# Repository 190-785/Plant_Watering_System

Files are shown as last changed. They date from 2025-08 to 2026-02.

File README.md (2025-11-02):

# Plant Watering System 🌱💧

An automated irrigation system using ESP8266 microcontrollers with soil moisture monitoring and intelligent watering control. Available in two versions: Basic IO and WiFi-enabled.

## Overview

This project consists of two main components with increasing levels of functionality:

### 1. IO Module (Basic Version)
A standalone irrigation controller that:
- Monitors soil moisture levels using an analog sensor
- Automatically controls a water pump based on moisture thresholds
- Provides real-time serial monitoring of system status
- Uses simple threshold-based logic for pump control

### 2. WiFi Module (Advanced Version)
An enhanced version with networking and cloud capabilities that includes:
- All basic irrigation functionality from the IO module
- WiFi connectivity with web-based configuration portal
- Firebase/Firestore integration for cloud data synchronization
- Real-time data synchronization to the cloud
- Remote configuration and control via Firebase
- Historical data logging and analytics
- Device-specific data paths using MAC address
- Web dashboard integration capabilities
- Data logging and remote monitoring capabilities
- Web server for system status and configuration
- JSON-based configuration management
- Button controls and LED status indicators
- Pump safety features and fault detection

## Hardware Requirements

### Core Components
- **Microcontroller**: ESP8266 (NodeMCU v2/v3)
- **Moisture Sensor**: Analog soil moisture sensor
- **Water Pump**: Small DC water pump (5V/12V)
- **Pump Driver**: ULN2003 or similar relay/driver circuit
- **Power Supply**: Appropriate for your pump voltage

### WiFi Version Additions
- **Push Button**: Momentary push button for manual controls
- **Status LED**: Single LED for status indication
- **WiFi Network**: 2.4GHz WiFi network for connectivity

### Wiring
- **Pump Control**: GPIO D1 (Pin 5) → ULN2003 IN1
- **Moisture Sensor**: A0 (Analog pin) → Sensor output
- **Button** (WiFi/Firebase): GPIO D2 (Pin 4) → Button + pull-up resistor
- **LED** (WiFi/Firebase): GPIO D3 (Pin 0) → LED anode
- **Power**: 3.3V/5V and GND connections as required

## Project Structure

```
Plant_Watering_System/
├── IO/                     # Basic irrigation system
│   ├── platformio.ini     # PlatformIO configuration
│   ├── src/
│   │   └── main.cpp       # Main irrigation logic
│   ├── include/           # Header files
│   └── lib/               # Local libraries
│
├── Wifi/                   # WiFi-enabled version
│   ├── platformio.ini     # PlatformIO configuration with WiFi libs
│   ├── src/
│   │   ├── main.cpp       # Main application with WiFi
│   │   ├── Config.cpp/h   # Configuration management
│   │   ├── ProvisionServer.cpp/h  # WiFi provisioning
│   │   └── PortalLogin.cpp/h      # Web portal authentication
│   ├── include/           # Header files
│   ├── lib/               # Local libraries
│   ├── HARDWARE_GUIDE.md  # Detailed hardware setup
│   ├── QUICK_REFERENCE.md # Quick reference card
│   ├── TESTING_MANUAL.md  # Manual testing procedures
│   └── TESTING_SIMULATION.md # Simulation testing guide
│
├── .gitignore             # Git ignore rules
├── LICENSE                # Project license
└── README.md              # This file
```

## Getting Started

### Prerequisites
- [PlatformIO IDE](https://platformio.org/platformio-ide) or [PlatformIO Core](https://platformio.org/install/cli)
- ESP8266 development board (NodeMCU recommended)
- Basic electronics components listed above

### Installation

1. **Clone the repository**:
   ```bash
   git clone https://github.com/190-785/Plant_Watering_System.git
   cd Plant_Watering_System
   ```

2. **Choose your version**:
   - For basic functionality: Navigate to `IO/` directory
   - For WiFi features: Navigate to `Wifi/` directory

3. **Build and upload**:
   ```bash
   # For basic version
   cd IO
   pio run --target upload

   # For WiFi version
   cd Wifi
   pio run --target upload
   ```

4. **Monitor serial output**:
   ```bash
   pio device monitor
   ```

### Configuration

#### Basic Version (IO)
- Power on the device near your plant
- Insert the moisture sensor into the soil
- Position the water pump in your water reservoir
- The system will automatically maintain optimal soil moisture

#### WiFi Version
1. **Initial Setup**: On first boot, the device creates a WiFi access point
2. **Connect**: Join the AP and navigate to the configuration portal
3. **Configure WiFi**: Set WiFi credentials and system parameters
4. **Firebase Setup** (Optional): Create a Firebase project and enable Firestore
5. **Configure Firebase** (Optional): Update `firebaseProjectId`, `firebaseApiKey`, and `firebaseDatabaseURL` in the code
6. **Deploy**: The system will connect to your network and begin operation, with optional cloud sync

## Features by Version

| Feature | IO | WiFi |
|---|----|---|
| Moisture monitoring | ✅ | ✅ |
| Automatic watering | ✅ | ✅ |
| Serial monitoring | ✅ | ✅ |
| Web interface | ❌ | ✅ |
| WiFi connectivity | ❌ | ✅ |
| Button controls | ❌ | ✅ |
| LED status | ❌ | ✅ |
| Pump safety | ❌ | ✅ |
| Data logging | ❌ | ✅ |
| Remote monitoring | ❌ | ✅ |
| Cloud sync | ❌ | ✅ |
| Historical data | ❌ | ✅ |

## Thresholds and Timing

### Moisture Control Logic
- **Dry Threshold**: 480-520 (triggers pump activation)
- **Wet Threshold**: 420-440 (stops pump operation)
- **Pump Runtime**: 1-2 seconds per cycle
- **Wait Period**: 1-2 minutes between pump cycles

### WiFi Version Features
- **Button Controls**: Triple-press (WiFi reset), Long-press (clear fault), Short-press (manual water)
- **LED Patterns**: 8 different status indicators
- **Web Endpoints**: Dashboard, status JSON, manual controls
- **Safety Features**: Pump interval enforcement, fault detection
- **Firebase Integration**: Real-time cloud synchronization, historical data logging
- **Device ID**: Auto-generated from MAC address
- **Data Paths**: `plantData/{deviceId}/` structure
- **Collections**: Live status, historical logs, remote config, commands
- **Sync Intervals**: Status every 10s, config check every 30s

## Documentation

### WiFi Version Documentation
- **[HARDWARE_GUIDE.md](Wifi/HARDWARE_GUIDE.md)** - Complete hardware setup and wiring
- **[QUICK_REFERENCE.md](Wifi/QUICK_REFERENCE.md)** - Quick reference card for controls and commands
- **[TESTING_MANUAL.md](Wifi/TESTING_MANUAL.md)** - Manual testing procedures and checklists
- **[TESTING_SIMULATION.md](Wifi/TESTING_SIMULATION.md)** - Simulation testing guide

## Customization

### Adjusting Thresholds
Modify the constants in `main.cpp`:
```cpp
constexpr uint16_t DRY_THRESHOLD = 520;  // Your dry value
constexpr uint16_t WET_THRESHOLD = 420;  // Your wet value
```

### Timing Adjustments
```cpp
const unsigned long PUMP_RUN_TIME = 1000;    // Pump duration (ms)
const unsigned long PUMP_WAIT_TIME = 60000;  // Wait between cycles (ms)
```

### WiFi Version Configuration
- **Portal Timeout**: 5 minutes for configuration
- **WiFi Retry**: Smart exponential backoff (1h → 6h → 24h)
- **Data Logging**: Every 30 seconds when online

### Firebase Configuration (WiFi Version)
Update these values in the WiFi version for cloud features:
```cpp
String firebaseProjectId = "your-project-id";
String firebaseApiKey = "your-api-key";
String firebaseDatabaseURL = "your-database-url";
```

## Troubleshooting

### Common Issues
- **Pump not activating**: Check wiring and power supply
- **Erratic readings**: Ensure sensor is properly inserted in soil
- **WiFi connection fails**: Verify credentials and signal strength
- **Continuous pumping**: Check sensor calibration and thresholds
- **Firebase sync fails**: Verify project credentials and permissions

### Version-Specific Issues

#### WiFi Version
- **Portal not appearing**: Triple-press button to force portal mode
- **LED not responding**: Check polarity (long leg to D3, short leg to GND)
- **Button not working**: Verify D2 connection and pull-up resistor
- **Firebase sync fails**: Check Firebase credentials and network connectivity
- **Device not appearing in Firebase**: Verify Firestore security rules
- **Firebase commands not working**: Check device ID format and collection paths

### Debugging
- Enable serial monitoring for detailed system status
- Check sensor readings manually with multimeter
- Verify pump operation with direct power connection
- Use the testing guides in the WiFi documentation

## Contributing

1. Fork the repository
2. Create a feature branch (`git checkout -b feature/amazing-feature`)
3. Commit your changes (`git commit -m 'Add amazing feature'`)
4. Push to the branch (`git push origin feature/amazing-feature`)
5. Open a Pull Request

## License

This project is licensed under the terms specified in the LICENSE file.

## Acknowledgments

- Built using PlatformIO and Arduino framework
- Designed for ESP8266 microcontrollers
- Inspired by the need for automated plant care solutions
- Firebase integration using Firebase Arduino Client Library

---

**Happy Growing! 🌱**

*Choose your version based on your needs:*
- **IO**: Simple, reliable, offline operation
- **WiFi**: Network connectivity, remote monitoring, and optional cloud features

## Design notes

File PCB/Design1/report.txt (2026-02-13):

Info: Processing symbol 'D1:LED_THT:LED_D5.0mm'.
Info: Processing symbol 'J1:Connector_PinHeader_2.54mm:PinHeader_1x02_P2.54mm_Vertical'.
Info: Processing symbol 'J2:Connector_PinHeader_2.54mm:PinHeader_1x03_P2.54mm_Vertical'.
Info: Processing symbol 'J3:Connector_PinHeader_2.54mm:PinHeader_1x15_P2.54mm_Vertical'.
Info: Processing symbol 'J4:Connector_PinHeader_2.54mm:PinHeader_1x15_P2.54mm_Vertical'.
Info: Processing symbol 'SW1:Button_Switch_THT:SW_PUSH-12mm'.
Info: Processing symbol 'U2:Package_DIP:DIP-16_W7.62mm'.
Info: Total warnings: 0, errors: 0.
Updated D1 symbol association from  to /114ef15a-0261-4e1b-b983-54d8c8b455e0.
Updated D1 fields.
Updated D1 sheetname to '/'.
Updated D1 sheetfile to 'Design1.kicad_sch'.
Updated D1 footprint filters to 'LED* LED_SMD:* LED_THT:*'.
Add net /3V3.
Connected D1 pin 1 to /3V3.
Add net unconnected-(D1-A-Pad2).
Connected D1 pin 2 to unconnected-(D1-A-Pad2).
Added J1 (footprint 'Connector_PinHeader_2.54mm:PinHeader_1x02_P2.54mm_Vertical').
Changed REF** reference designator to J1.
Changed J1 value from PinHeader_1x02_P2.54mm_Vertical to Screw_Terminal_01x02.
Updated J1 symbol association from  to /084adaf7-5e28-4bd0-8539-3aa2166aa7e4.
Updated J1 sheetname to '/'.
Updated J1 sheetfile to 'Design1.kicad_sch'.
Updated J1 footprint filters to 'TerminalBlock*:*'.
Connected J1 pin 1 to /3V3.
Connected J1 pin 2 to /3V3.
Added J2 (footprint 'Connector_PinHeader_2.54mm:PinHeader_1x03_P2.54mm_Vertical').
Changed REF** reference designator to J2.
Changed J2 value from PinHeader_1x03_P2.54mm_Vertical to Screw_Terminal_01x03.
Updated J2 symbol association from  to /2fd5f57d-fc6a-4e79-a7f4-4b87a4e682fe.
Updated J2 fields.
Updated J2 sheetname to '/'.
Updated J2 sheetfile to 'Design1.kicad_sch'.
Updated J2 footprint filters to 'TerminalBlock*:*'.
Connected J2 pin 2 to /3V3.
Connected J2 pin 1 to /3V3.
Connected J2 pin 3 to /3V3.
Updated J1 fields.
Added J3 (footprint 'Connector_PinHeader_2.54mm:PinHeader_1x15_P2.54mm_Vertical').
Changed REF** reference designator to J3.
Changed J3 value from PinHeader_1x15_P2.54mm_Vertical to Conn_01x15.
Updated J3 symbol association from  to /b5223ff5-7ecc-4eef-a9c0-85b9987116a3.
Updated J3 fields.
Updated J3 sheetname to '/'.
Updated J3 sheetfile to 'Design1.kicad_sch'.
Updated J3 footprint filters to 'Connector*:*_1x??_*'.
Add net /RX.
Connected J3 pin 4 to /RX.
Connected J3 pin 9 to /3V3.
Connected J3 pin 10 to /3V3.
Add net /TX.
Connected J3 pin 3 to /TX.
Connected J3 pin 14 to /3V3.
Add net /D8.
Connected J3 pin 5 to /D8.
Connected J3 pin 12 to /3V3.
Add net /D5.
Connected J3 pin 8 to /D5.
Add net /D0&apos;.
Connected J3 pin 15 to /D0&apos;.
Add net /D4.
Connected J3 pin 11 to /D4.
Add net /D6.
Connected J3 pin 7 to /D6.
Add net /D7.
Connected J3 pin 6 to /D7.
Connected J3 pin 1 to /3V3.
Add net /D2.
Connected J3 pin 13 to /D2.
Connected J3 pin 2 to /3V3.
Added J4 (footprint 'Connector_PinHeader_2.54mm:PinHeader_1x15_P2.54mm_Vertical').
Changed REF** reference designator to J4.
Changed J4 value from PinHeader_1x15_P2.54mm_Vertical to Conn_01x15.
Updated J4 symbol association from  to /26412373-530a-4317-82af-74bdb8bcc9cc.
Updated J4 fields.
Updated J4 sheetname to '/'.
Updated J4 sheetfile to 'Design1.kicad_sch'.
Updated J4 footprint filters to 'Connector*:*_1x??_*'.
Connected J4 pin 2 to /3V3.
Connected J4 pin 6 to /3V3.
Connected J4 pin 8 to /3V3.
Connected J4 pin 12 to /3V3.
Connected J4 pin 13 to /3V3.
Connected J4 pin 15 to /3V3.
Connected J4 pin 9 to /3V3.
Connected J4 pin 5 to /3V3.
Connected J4 pin 4 to /3V3.
Connected J4 pin 14 to /3V3.
Connected J4 pin 11 to /3V3.
Connected J4 pin 1 to /3V3.
Connected J4 pin 10 to /3V3.
Add net unconnected-(J4-Pin_3-Pad3).
Connected J4 pin 3 to unconnected-(J4-Pin_3-Pad3).
Connected J4 pin 7 to /3V3.
Added D1 (footprint 'LED_THT:LED_D5.0mm').
Added SW1 (footprint 'Button_Switch_THT:SW_PUSH-12mm').
Changed REF** reference designator to SW1.
Changed SW1 value from SW_PUSH-12mm to SW_Push.
Updated SW1 symbol association from  to /c2e4434d-4b0b-49ac-be75-4c2e37a08468.
Updated SW1 fields.
Updated SW1 sheetname to '/'.
Updated SW1 sheetfile to 'Design1.kicad_sch'.
Connected SW1 pin 2 to /3V3.
Connected SW1 pin 1 to /3V3.
Connected SW1 pin 1 to /3V3.
Connected SW1 pin 2 to /3V3.
Changed REF** reference designator to D1.
Added U2 (footprint 'Package_DIP:DIP-16_W7.62mm').
Changed REF** reference designator to U2.
Changed U2 value from DIP-16_W7.62mm to ULN2003.
Updated U2 symbol association from  to /411cef7f-ac7a-48d0-bb4d-53be7344f0cd.
Changed D1 value from LED_D5.0mm to LED.
Updated U2 sheetname to '/'.
Updated U2 sheetfile to 'Design1.kicad_sch'.
Updated U2 footprint filters to 'DIP*W7.62mm* SOIC*3.9x9.9mm*P1.27mm* SSOP*4.4x5.2mm*P0.65mm* TSSOP*4.4x5mm*P0.65mm* SOIC*W*5.3x10.2mm*P1.27mm*'.
Add net unconnected-(U2-I4-Pad4).
Connected U2 pin 4 to unconnected-(U2-I4-Pad4).
Add net unconnected-(U2-I6-Pad6).
Connected U2 pin 6 to unconnected-(U2-I6-Pad6).
Add net unconnected-(U2-I2-Pad2).
Connected U2 pin 2 to unconnected-(U2-I2-Pad2).
Add net unconnected-(U2-O2-Pad15).
Connected U2 pin 15 to unconnected-(U2-O2-Pad15).
Add net unconnected-(U2-O7-Pad10).
Connected U2 pin 10 to unconnected-(U2-O7-Pad10).
Add net unconnected-(U2-COM-Pad9).
Connected U2 pin 9 to unconnected-(U2-COM-Pad9).
Connected U2 pin 1 to /3V3.
Add net unconnected-(U2-O3-Pad14).
Updated U2 fields.
Add net unconnected-(U2-O6-Pad11).
Connected U2 pin 11 to unconnected-(U2-O6-Pad11).
Add net unconnected-(U2-GND-Pad8).
Connected U2 pin 8 to unconnected-(U2-GND-Pad8).
Add net unconnected-(U2-O5-Pad12).
Connected U2 pin 12 to unconnected-(U2-O5-Pad12).
Add net unconnected-(U2-I3-Pad3).
Connected U2 pin 3 to unconnected-(U2-I3-Pad3).
Add net unconnected-(U2-I7-Pad7).
Connected U2 pin 7 to unconnected-(U2-I7-Pad7).
Add net unconnected-(U2-O4-Pad13).
Connected U2 pin 13 to unconnected-(U2-O4-Pad13).
Connected U2 pin 16 to /3V3.
Add net unconnected-(U2-I5-Pad5).
Connected U2 pin 5 to unconnected-(U2-I5-Pad5).

Connected U2 pin 14 to unconnected-(U2-O3-Pad14).

Info: Total warnings: 0, errors: 0.

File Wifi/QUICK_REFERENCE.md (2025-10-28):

# Quick Reference Card - Smart Irrigation System v3.0

## 🎮 Button Controls (D2)
```
┌─────────────────────────────────────────────┐
│  Triple Press  │ 3 clicks in 2 seconds      │ → WiFi Reset
│  Long Press    │ Hold 5+ seconds            │ → Clear Fault  
│  Short Press   │ Quick click                │ → Manual Water
└─────────────────────────────────────────────┘
```

## 💡 LED Patterns (D3)
```
Portal Active    ●●──●●──  Fast double-blink
Connecting       ●───●───  Fast blink
Online           ●────────  Slow heartbeat (every 3s)
Offline          ●────────  Slow blink (every 3s)
Pumping          ████████  Solid on
Fault            ●●────●●  Error blink
Button Feedback  ●●●       Three flashes
```

## 📍 Pin Mapping
```
D1 → Pump (via ULN2003)
D2 → Button (+ pull-up)
D3 → LED Anode
A0 → Moisture Sensor
```

## 🌐 Network
```
AP Name:  Irrigation-Setup
Password: plant123456
Web UI:   http://{device-ip}/
```

## 🔗 Web Endpoints
```
GET  /         → Dashboard
GET  /status   → JSON status
POST /water    → Manual water
POST /clearFault → Clear fault
POST /resetWiFi → Reset config
```

## 📊 Firestore Paths
```
plantData/{deviceId}/
  ├── (document)           → Live status
  ├── logs/{timestamp}     → Historical data
  ├── config/settings      → Configuration
  └── commands/pending     → Remote commands
```

## ⚙️ Default Config (Testing)
```
Dry Threshold:   520
Wet Threshold:   420
Pump Run Time:   2000 ms (2 sec)
Min Interval:    60 sec (1 min)
No-Effect Max:   2 failures
Settle Time:     10000 ms (10 sec)
```

## 🔄 State Transitions
```
AWAITING_CONFIG → ONLINE → OFFLINE ⟲
                    ↓
              LOCKED_FAULT (clearable)
```

## 🚨 Common Issues
```
No WiFi      → Triple-press button
Pump stuck   → Check ULN2003 wiring
Fault locked → Long-press 5 seconds
LED wrong    → Check polarity (long leg = +)
```

## 📝 Serial Monitor Commands
```
115200 baud
Look for:
  ✓ = Success
  ✗ = Error
  ⚠ = Warning
  [STATUS] = Regular update
  [BUTTON] = Button event
  [WiFi] = Network event
```

## 🎯 Quick Test Sequence
```
1. Power on
2. Watch LED (should show portal or connecting)
3. Press button once (LED should flash 3x)
4. Check serial for "BUTTON Short press"
5. Dry sensor (should auto-water)
6. Check Firebase console for logs
```

## 📱 Firebase Update Example
```javascript
// Update config
db.collection('plantData')
  .doc(deviceId)
  .collection('config')
  .doc('settings')
  .update({
    dryThreshold: 530,
    pumpRunTime: 5000
  });

// Clear fault
db.collection('plantData')
  .doc(deviceId)
  .collection('commands')
  .doc('pending')
  .set({
    clearFault: true
  });
```

## 🔐 Default Credentials
```
Firebase Project: bloom-watch-d6878
API Key: AIzaSyCt74... (in code)
Device ID: ESP8266_{MAC} (auto-generated)
```

## ⏱️ Timing Reference
```
Data Send:        Every 10 seconds
Config Check:     Every 30 seconds
Status Display:   Every 3 seconds
WiFi Check:       Every 5 seconds
Smart Retry:      1h → 6h → 24h
Portal Timeout:   5 minutes
```

## 💾 Files
```
/config.json       → WiFi & Firebase creds
/pump_state.json   → Pump history & faults
```

## 🛠️ Build Commands
```
pio run --target upload    → Flash device
pio device monitor         → View serial
pio run --target clean     → Clean build
```

## 📞 Emergency Recovery
```
1. Triple-press button → Force portal
2. Connect to "Irrigation-Setup"
3. Reconfigure WiFi
4. Or: Flash with USB cable
```

## ✅ Deployment Checklist
```
□ Hardware connected per diagram
□ Firebase credentials verified
□ Libraries installed
□ Code compiles
□ First boot shows portal
□ WiFi connects
□ LED shows correct pattern
□ Button presses register
□ Pump activates
□ Firebase logs appear
□ Web interface accessible
```

---

**Keep this card handy during testing!** 📋

Print or save for quick reference while working with your device.

Version: 3.0 Phase 1 | ESP8266 NodeMCU | Firebase Firestore

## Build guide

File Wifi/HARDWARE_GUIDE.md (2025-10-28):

# Hardware Connection Guide
## Smart Irrigation System - ESP8266 NodeMCU

```
┌─────────────────────────────────────────────────────────────┐
│                     HARDWARE WIRING DIAGRAM                  │
└─────────────────────────────────────────────────────────────┘

╔═══════════════════════════════════════════════════════════╗
║                    NodeMCU ESP8266                         ║
║                                                            ║
║  [USB] ←── Power & Programming                            ║
║                                                            ║
║  3V3  ●────────────────────────┐                          ║
║                                 │                          ║
║  GND  ●──────┬──────┬──────────┼──────┬──────────┐       ║
║              │      │          │      │          │       ║
║  VIN  ●──────┼──────┼──────────┼──────┼────┐     │       ║
║              │      │          │      │    │     │       ║
║   D1  ●──────┼──────┼────┐     │      │    │     │       ║
║              │      │    │     │      │    │     │       ║
║   D2  ●──────┼──────┼────┼────┐│      │    │     │       ║
║              │      │    │     ││      │    │     │       ║
║   D3  ●──────┼──────┼────┼────┼┼────┐ │    │     │       ║
║              │      │    │     ││    │ │    │     │       ║
║   A0  ●──────┼──────┼────┼────┼┼────┼─┼────┼───┐ │       ║
║              │      │    │     ││    │ │    │   │ │       ║
╚══════════════╪══════╪════╪═════╪╪════╪═╪════╪═══╪═╪═══════╝
               │      │    │     ││    │ │    │   │ │
               │      │    │     ││    │ │    │   │ │
    ┌──────────┘      │    │     ││    │ │    │   │ │
    │                 │    │     ││    │ │    │   │ │
╔═══▼═════════════════▼════▼═════▼▼════▼═▼════▼═══▼═▼═══════╗
║              ULN2003 Darlington Driver                      ║
╠═══════════════════════════════════════════════════════════╣
║  IN1  (from D1)                                            ║
║  IN2-7  (not used)                                         ║
║  GND   (from NodeMCU GND)                                  ║
║  COM   (from NodeMCU VIN)  ←── Power for pump             ║
║  OUT1  ────────┐                                           ║
╚════════════════╪═══════════════════════════════════════════╝
                 │
                 │         ╔════════════════════╗
                 └────────→║   WATER PUMP       ║
                           ║   Pin 1: Signal    ║
                           ║   Pin 2: VIN       ║
                           ╚════════════════════╝

╔═══════════════════════════════════════════════════════════╗
║              Capacitive Moisture Sensor                    ║
╠═══════════════════════════════════════════════════════════╣
║  VCC  → NodeMCU 3V3                                        ║
║  GND  → NodeMCU GND                                        ║
║  AOUT → NodeMCU A0                                         ║
╚═══════════════════════════════════════════════════════════╝

╔═══════════════════════════════════════════════════════════╗
║                Manual Control Button                       ║
╠═══════════════════════════════════════════════════════════╣
║  Terminal 1 → NodeMCU D2                                   ║
║  Terminal 2 → NodeMCU GND                                  ║
║                                                            ║
║  Note: Internal pull-up enabled in software               ║
╚═══════════════════════════════════════════════════════════╝

╔═══════════════════════════════════════════════════════════╗
║                    Status LED                              ║
╠═══════════════════════════════════════════════════════════╣
║  Anode (+, long leg)  → NodeMCU D3                        ║
║  Cathode (-, short leg) → NodeMCU GND                     ║
║                                                            ║
║  Note: Built-in current limiting in ESP8266 GPIO          ║
║        If LED too bright, add 220Ω resistor in series     ║
╚═══════════════════════════════════════════════════════════╝
```

---

## Pin Summary Table

| Component | NodeMCU Pin | Wire Color (Suggested) | Notes |
|---|---|---|---|
| **Pump Control** | D1 | Yellow | To ULN2003 IN1 |
| **Moisture Sensor**| A0 | White | Analog reading |
| **Button** | D2 | Blue | Pull-up enabled |
| **Status LED** | D3 | Green | Anode (long leg) |
| **Sensor VCC** | 3V3 | Red | 3.3V power |
| **Common Ground**  | GND | Black | Multiple connections |
| **Pump Power** | VIN | Red (thick) | 5V from USB |

---

## Component Details

### 1. ULN2003 Darlington Driver Pinout
```
        ┌─────────┐
   IN1 →│1      16│→ OUT1 (to pump)
   IN2 →│2      15│
   IN3 →│3      14│
   IN4 →│4      13│
   IN5 →│5      12│
   IN6 →│6      11│
   IN7 →│7      10│
   GND ─│8       9│─ COM (VIN power)
        └─────────┘
```

### 2. Button Wiring Options
```
Option A: Simple (Used in Code)
┌──────┐
│  D2  ●───────┬─── Button Terminal 1
│      │       │
│ GND  ●───────┴─── Button Terminal 2
└──────┘
Internal pull-up: Button not pressed = HIGH, pressed = LOW

Option B: External Pull-up (if internal not reliable)
┌──────┐
│ 3V3  ●─── 10kΩ resistor ───┬─── Button Terminal 1
│      │                      │
│  D2  ●──────────────────────┤
│      │                      │
│ GND  ●──────────────────────┴─── Button Terminal 2
└──────┘
```

### 3. LED Polarity Identification
```
        LED
    ┌────────┐
    │  ╱╲    │
    │ ╱  ╲   │ ← Flat edge on cathode side
    │╱____╲  │
    │   ||   │
    │   ||   │
    └───┬┬───┘
        ││
    Long│  Short
  (Anode)  (Cathode)
     +       -
     D3     GND
```

---

## Testing Individual Components

### Test 1: LED
```cpp
void setup() {
  pinMode(D3, OUTPUT);
}
void loop() {
  digitalWrite(D3, HIGH);
  delay(1000);
  digitalWrite(D3, LOW);
  delay(1000);
}
```
**Expected:** LED blinks on/off every second

### Test 2: Button
```cpp
void setup() {
  Serial.begin(115200);
  pinMode(D2, INPUT_PULLUP);
}
void loop() {
  Serial.println(digitalRead(D2));
  delay(100);
}
```
**Expected:** Prints "1" normally, "0" when button pressed

### Test 3: Moisture Sensor
```cpp
void setup() {
  Serial.begin(115200);
}
void loop() {
  Serial.println(analogRead(A0));
  delay(500);
}
```
**Expected:** 
- In air: ~800-1024
- In water: ~200-400
- In moist soil: ~400-600
- In dry soil: ~600-800

### Test 4: Pump (CAREFUL!)
```cpp
void setup() {
  pinMode(D1, OUTPUT);
  digitalWrite(D1, LOW);
}
void loop() {
  digitalWrite(D1, HIGH);  // ON
  delay(2000);
  digitalWrite(D1, LOW);   // OFF
  delay(10000);
}
```
**Expected:** Pump runs 2 seconds, off 10 seconds, repeat
**WARNING:** Have water reservoir connected!

---

## Power Requirements

| Component | Voltage | Current | Source |
|---|---|---|---|
| ESP8266 NodeMCU | 3.3V | ~80mA | USB 5V (onboard regulator) |
| Moisture Sensor | 3.3V | ~5mA | NodeMCU 3V3 |
| LED | 2-3V | ~20mA | NodeMCU D3 |
| Button | 3.3V | <1mA | NodeMCU D2 |
| Water Pump (typical) | 3-6V | 100-200mA | USB 5V (VIN)  |
| ULN2003 (driver IC) | 5V | <1mA | NodeMCU VIN |

**Total Current Draw:**
- Idle: ~85mA
- Pump Running: ~285mA
- **USB Port Limit:** 500mA (safe margin)

---

## Common Issues & Solutions

### Issue: Pump doesn't run
**Solutions:**
1. Check D1 connection to ULN2003 IN1
2. Verify ULN2003 GND connected to NodeMCU GND
3. Verify ULN2003 COM connected to NodeMCU VIN
4. Check pump polarity (try reversing if DC pump)
5. Test with multimeter: Should see ~5V on OUT1 when D1 HIGH

### Issue: LED always on/off
**Solutions:**
1. Check LED polarity (swap if backwards)
2. Verify anode (long leg) to D3
3. Verify cathode (short leg) to GND
4. Test with: `digitalWrite(D3, HIGH);` in setup()

### Issue: Button always pressed/never pressed
**Solutions:**
1. Check wiring: One side D2, other side GND
2. Try different button (could be faulty)
3. Test with multimeter: Should be open circuit normally, closed when pressed

### Issue: Moisture readings don't change
**Solutions:**
1. Verify sensor VCC to 3V3 (NOT 5V!)
2. Check AOUT to A0 connection
3. Check GND connection
4. Test in glass of water - should drop significantly

### Issue: ESP8266 resets when pump runs
**Solutions:**
1. Likely power issue - pump drawing too much current
2. Add capacitor (100µF-1000µF) across VIN and GND
3. Use separate 5V power supply for pump
4. Reduce pump runtime or use smaller pump

---

## Safety Checklist

- [ ] All connections secure (no loose wires)
- [ ] No exposed metal touching other components
- [ ] Moisture sensor fully waterproof (only prongs in soil/water)
- [ ] Water reservoir below electronics (prevent spills on board)
- [ ] USB power supply rated for 1A or higher
- [ ] No water near USB port or ESP8266
- [ ] Pump has water to pump (don't run dry)
- [ ] First test without water, verify pump spins

---

## Recommended Tools

- **Multimeter** - For voltage/continuity testing
- **Breadboard** - For prototyping before soldering
- **Jumper Wires** - Male-to-male, male-to-female
- **USB Cable** - Micro USB for NodeMCU power/programming
- **Screwdriver** - For ULN2003 terminal blocks
- **Wire Strippers** - If using solid core wire

---

## Final Assembly Tips

1. **Test each component individually first** (see test code above)
2. **Use breadboard for initial testing** before permanent connections
3. **Label all wires** with masking tape (component name + pin)
4. **Take photos** of working setup before making changes
5. **Keep moisture sensor away from electronics**
6. **Mount NodeMCU above water level**
7. **Use cable ties** to organize wires
8. **Add strain relief** on USB cable

---

**All connections verified against system design specification.**

Ready to build! 🛠️

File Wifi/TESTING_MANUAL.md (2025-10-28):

# 🧪 Smart Irrigation System - Manual Test Plan (Phase 1)

## 📋 Test Overview
This document provides a comprehensive manual testing checklist for all Phase 1 features. Each test includes:
- **Prerequisites** - What needs to be ready
- **Steps** - Exact procedure to follow
- **Expected Result** - What should happen
- **Pass/Fail Criteria** - How to verify success

---

## 🔧 Pre-Test Setup

### Hardware Checklist
- [ ] ESP8266 NodeMCU connected via USB
- [ ] Button connected to D2 (GPIO4) with pull-up resistor
- [ ] LED connected to D3 (GPIO0) with current-limiting resistor
- [ ] Pump connected to D1 (GPIO5) via ULN2003 driver
- [ ] Moisture sensor connected to A0
- [ ] Power supply adequate for all components

### Software Checklist
- [ ] Code uploaded successfully (no compilation errors)
- [ ] Serial monitor open at 115200 baud
- [ ] Firebase console open: https://console.firebase.google.com/project/bloom-watch-d6878/firestore
- [ ] Device ID noted from serial output (ESP8266_XXXXXXXXXXXX)

---

## ✅ TEST SUITE 1: INITIALIZATION & BOOT

### Test 1.1: First Boot (No Config)
**Prerequisites:** Flash empty filesystem (erase flash)
```bash
pio run --target erase
pio run --target upload
```

**Steps:**
1. Reset ESP8266
2. Observe serial output
3. Check LED pattern

**Expected Results:**
```
✓ LittleFS mounted successfully
Device ID: ESP8266_C82B9622AF07
ℹ No config file found - will create on first WiFi connection
ℹ No WiFi config - starting portal
*wm:StartAP with SSID: Irrigation-Setup
*wm:AP IP address: 192.168.4.1
```
- LED shows **fast double-blink** (100ms on, 100ms off, 100ms on, 700ms off)
- WiFi AP "Irrigation-Setup" visible in WiFi list

**Pass Criteria:**
- [ ] Portal AP broadcasts
- [ ] LED shows correct pattern
- [ ] Serial shows no errors

---

### Test 1.2: Boot with Saved Config
**Prerequisites:** WiFi already configured

**Steps:**
1. Reset ESP8266
2. Observe connection sequence

**Expected Results:**
```
✓ Configuration loaded
✓ Attempting WiFi connection...
✓ Connected! IP: 192.168.x.x
✓ Web server started on port 80
State: ONLINE
```
- LED shows **slow heartbeat** (100ms pulse every 3 seconds)
- Device connects to WiFi within 30 seconds

**Pass Criteria:**
- [ ] Connects to saved WiFi
- [ ] Gets IP address
- [ ] Shows ONLINE state
- [ ] LED heartbeat visible

---

## ✅ TEST SUITE 2: BUTTON CONTROLS

### Test 2.1: Short Press (Manual Water)
**Prerequisites:** Device ONLINE, no fault, >60 seconds since last pump

**Steps:**
1. Press and release button quickly (< 1 second)
2. Observe LED feedback
3. Watch for pump activation
4. Check serial output

**Expected Results:**
```
[BUTTON] Short press detected
[PUMP] Manual activation requested
[PUMP] Starting pump (Manual)
[STATUS] Moisture: XXX | Pump: PUMP_RUNNING | Device: ONLINE
```
- LED flashes 3 times quickly (button feedback)
- LED goes solid for 2 seconds (pumping)
- Pump relay activates for 2 seconds
- Returns to MONITORING state

**Pass Criteria:**
- [ ] Button feedback visible
- [ ] Pump runs for exactly 2 seconds
- [ ] Moisture reading taken before/after
- [ ] Logged to Firestore

---

### Test 2.2: Long Press (Clear Fault)
**Prerequisites:** Device in LOCKED_FAULT state

**Steps:**
1. Create fault condition (trigger no-effect detection twice)
2. Press and hold button for 5+ seconds
3. Release button
4. Observe state change

**Expected Results:**
```
[BUTTON] Long press detected
[FAULT] Clearing fault state
✓ Fault cleared via button
State: ONLINE
```
- LED changes from slow error blink to heartbeat
- Fault counter resets to 0
- Device returns to ONLINE state
- Pump state saved to flash

**Pass Criteria:**
- [ ] Fault clears after 5 seconds hold
- [ ] State changes to ONLINE
- [ ] LED pattern updates
- [ ] pump_state.json updated

---

### Test 2.3: Triple Press (WiFi Reset)
**Prerequisites:** Device running (any state)

**Steps:**
1. Press button 3 times within 2 seconds
2. Wait for portal to start
3. Check WiFi AP list

**Expected Results:**
```
[BUTTON] Triple press detected
[WiFi] Force configuration portal
*wm:StartAP with SSID: Irrigation-Setup
State: AWAITING_CONFIG
```
- LED switches to fast double-blink
- "Irrigation-Setup" AP appears
- Web portal accessible at 192.168.4.1
- Can reconfigure WiFi

**Pass Criteria:**
- [ ] Portal starts immediately
- [ ] AP broadcasts within 5 seconds
- [ ] Portal accessible
- [ ] Can save new config

---

## ✅ TEST SUITE 3: LED PATTERNS

### Test 3.1: All LED Patterns Visual Verification

| State | Pattern | Timing | How to Trigger |
|---|---|---|---|
| **Portal Active** | Fast double-blink | 100ms on, 100ms off, 100ms on, 700ms off | Triple press button |
| **Connecting** | Fast single blink | 200ms on, 800ms off | Reboot with WiFi config, disconnect router |
| **Online** | Slow heartbeat | 100ms on every 3000ms | Normal operation when connected |
| **Offline** | Single blink | 500ms on every 3000ms | Disconnect WiFi router |
| **Pumping** | Solid on | Continuous | Trigger manual water or auto water |
| **Fault** | Slow error blink | 500ms on, 1500ms off | Trigger fault (2x no-effect) |
| **Button Feedback** | Three quick flashes | 50ms on/off x3 | Press any button |
| **Off** | No light | - | Not used in Phase 1 |

**Steps:**
1. For each state, trigger the condition
2. Use stopwatch/timer to verify exact timing
3. Record visual observation

**Pass Criteria:**
- [ ] All 8 patterns visually distinct
- [ ] Timing matches specification ±10ms
- [ ] Patterns persist correctly
- [ ] Transitions smooth

---

## ✅ TEST SUITE 4: PUMP SAFETY LOGIC

### Test 4.1: Minimum Interval Enforcement (AUTO)
**Prerequisites:** Device ONLINE, dry soil (moisture < 520)

**Steps:**
1. Allow auto-watering to trigger
2. Immediately trigger auto again (dry sensor reading)
3. Check serial output

**Expected Results:**
```
[PUMP] Auto activation requested
[SAFETY] minInterval not met: 30/60 seconds elapsed
```
- Pump does NOT activate second time
- Must wait full 60 seconds
- LED does not show pumping pattern

**Pass Criteria:**
- [ ] Second pump attempt blocked
- [ ] Serial shows safety message
- [ ] Wait 60s → then pump works

---

### Test 4.2: Minimum Interval Enforcement (MANUAL)
**Prerequisites:** Device ONLINE

**Steps:**
1. Short press button (manual water)
2. Wait for pump to finish
3. Immediately short press again
4. Check response

**Expected Results:**
```
[PUMP] Manual activation requested
[SAFETY] minInterval not met: 5/60 seconds elapsed
```
- Second manual request blocked
- Same 60-second rule applies
- Button feedback still shows

**Pass Criteria:**
- [ ] Manual also respects minInterval
- [ ] Safety message appears
- [ ] No pump activation

---

### Test 4.3: No-Effect Detection (First Occurrence)
**Prerequisites:** Device ONLINE, moisture sensor NOT in water

**Steps:**
1. Place sensor in dry air (not in soil)
2. Trigger manual water (short press)
3. Wait for pump to run and settle (12 seconds total)
4. Check serial output

**Expected Results:**
```
[PUMP] Starting pump (Manual)
[PUMP] Before: 100, After: 105, Delta: 5
⚠ Pump ineffective! No significant moisture change (5 < 30)
⚠ No-effect count: 1/2
```
- No-effect counter increments to 1
- Device stays in ONLINE state
- Pump state saved
- Still allows next watering attempt

**Pass Criteria:**
- [ ] Delta calculated correctly
- [ ] Counter = 1 (not locked yet)
- [ ] State remains ONLINE
- [ ] pump_state.json shows noEffectCounter: 1

---

### Test 4.4: Fault Locking (Second No-Effect)
**Prerequisites:** No-effect counter = 1

**Steps:**
1. Wait 60+ seconds (minInterval)
2. Sensor still dry (no water)
3. Trigger manual water again
4. Observe state change

**Expected Results:**
```
[PUMP] Before: 100, After: 103, Delta: 3
⚠ Pump ineffective! No significant moisture change (3 < 30)
⚠ No-effect count: 2/2
🚨 FAULT LOCKED - Too many ineffective pump cycles!
State: LOCKED_FAULT
```
- LED switches to slow error blink (500ms/1500ms)
- Device enters LOCKED_FAULT state
- Auto watering disabled
- Manual watering disabled
- Fault persists across reboots

**Pass Criteria:**
- [ ] Counter reaches 2
- [ ] State = LOCKED_FAULT
- [ ] LED error pattern
- [ ] Persists after reboot
- [ ] Pump blocked for all triggers

---

### Test 4.5: Fault Recovery
**Prerequisites:** Device in LOCKED_FAULT

**Steps:**
1. Long press button (5 seconds)
2. Observe state change
3. Reset device
4. Check state persists

**Expected Results:**
```
[BUTTON] Long press detected
[FAULT] Clearing fault state
✓ Fault cleared via button
State: ONLINE
```
- Counter resets to 0
- Device returns to ONLINE
- LED shows heartbeat
- pump_state.json updated

**Pass Criteria:**
- [ ] Fault clears successfully
- [ ] Counter = 0
- [ ] State = ONLINE after reboot
- [ ] Can pump again (respecting minInterval)

---

## ✅ TEST SUITE 5: WIFI & CONNECTIVITY

### Test 5.1: WiFi Portal Configuration
**Prerequisites:** Fresh device or triple-press to reset

**Steps:**
1. Connect phone/PC to "Irrigation-Setup" AP
2. Password: plant123456
3. Browser should auto-open to 192.168.4.1
4. Configure WiFi network
5. Click "Save"

**Expected Results:**
- Portal loads showing available networks
- Can select network and enter password
- After save, device reboots and connects
- config.json created in filesystem

**Pass Criteria:**
- [ ] Portal accessible
- [ ] Networks listed
- [ ] Can save configuration
- [ ] Device connects after save

---

### Test 5.2: Smart Retry - First Failure (1 hour)
**Prerequisites:** Device connected to WiFi

**Steps:**
1. Disconnect/turn off router
2. Observe retry behavior
3. Check serial output timing

**Expected Results:**
```
✗ WiFi connection lost
State: OFFLINE
Retry attempt: 1, Next retry in: 60 minutes
```
- Device switches to OFFLINE
- LED shows single blink pattern
- Retries connection after 1 hour
- Core functions continue locally

**Pass Criteria:**
- [ ] Detects disconnect within 30s
- [ ] State = OFFLINE
- [ ] Retry scheduled for 1 hour
- [ ] Sensor readings continue

---

### Test 5.3: Smart Retry - Second Failure (6 hours)
**Prerequisites:** First retry failed

**Steps:**
1. Keep router off
2. Wait for first retry (1 hour)
3. Let it fail again
4. Check next retry interval

**Expected Results:**
```
Retry attempt: 2, Next retry in: 360 minutes
```
- Retry interval increases to 6 hours
- Device stays in OFFLINE
- Local operation continues

**Pass Criteria:**
- [ ] Second retry at 1 hour mark
- [ ] Next retry = 6 hours
- [ ] No continuous retry spam

---

### Test 5.4: Smart Retry - Success Recovery
**Prerequisites:** Device in retry loop

**Steps:**
1. Turn router back on
2. Wait for next scheduled retry
3. Observe reconnection

**Expected Results:**
```
✓ WiFi reconnected!
State: ONLINE
Retry count reset to 0
```
- Reconnects successfully
- Retry counter resets
- Firebase sync resumes
- LED returns to heartbeat

**Pass Criteria:**
- [ ] Connects on retry
- [ ] State = ONLINE
- [ ] Retry count = 0
- [ ] Firestore logs resume

---

## ✅ TEST SUITE 6: FIRESTORE INTEGRATION

### Test 6.1: Log Entry Creation
**Prerequisites:** Device ONLINE, Firebase console open

**Steps:**
1. Navigate to: Firestore > plantData > ESP8266_{YOUR_MAC} > logs
2. Trigger manual water (short press)
3. Wait 2-3 seconds
4. Refresh Firestore console

**Expected Results:**
- New document appears in logs subcollection
- Document ID is timestamp
- Fields present:
  - `moisture` (integer)
  - `pumpStatus` (string: "PUMP_RUNNING")
  - `activationMethod` (string: "Manual")
  - `deviceState` (string: "ONLINE")

**Pass Criteria:**
- [ ] Document created within 3 seconds
- [ ] All fields present and correct types
- [ ] Moisture value matches serial output
- [ ] No HTTP errors in serial

---

### Test 6.2: Device Status Updates (Heartbeat)
**Prerequisites:** Device ONLINE

**Steps:**
1. Navigate to: Firestore > plantData > ESP8266_{YOUR_MAC}
2. Watch the main document (not logs subcollection)
3. Observe field updates every 10 seconds

**Expected Results:**
Main document fields:
- `currentMoisture` (integer, updates every 10s)
- `currentPumpStatus` (string: "MONITORING" / "PUMP_RUNNING" / "PUMP_WAITING")
- `lockedFault` (boolean: false / true)
- `lastSeen` (timestamp, updates every 10s)

**Pass Criteria:**
- [ ] Main document exists
- [ ] lastSeen updates every ~10s
- [ ] currentMoisture matches sensor
- [ ] lockedFault reflects device state

---

### Test 6.3: Config Sync (Remote Update)
**Prerequisites:** Device ONLINE

**Steps:**
1. In Firestore, navigate to: plantData/{deviceId}/config/settings
2. Create document if not exists
3. Set fields:
   ```
   dryThreshold: 400 (integer)
   wetThreshold: 700 (integer)
   pumpRunTime: 3000 (integer)
   minIntervalSec: 120 (integer)
   ```
4. Save document
5. Wait up to 30 seconds
6. Check serial output

**Expected Results:**
```
[CONFIG] Update detected from Firestore
  dryThreshold: 520 → 400
  wetThreshold: 750 → 700
  pumpRunTime: 2000 → 3000
  minIntervalSec: 60 → 120
✓ Configuration updated
```
- Device syncs new values within 30 seconds
- Values take effect immediately
- config.json updated in filesystem

**Pass Criteria:**
- [ ] Sync happens within 30s
- [ ] All values update correctly
- [ ] Next pump uses new pumpRunTime (3s)
- [ ] config.json shows new values

---

### Test 6.4: Remote Fault Clear
**Prerequisites:** Device in LOCKED_FAULT state

**Steps:**
1. In Firestore: plantData/{deviceId}/commands/pending
2. Create document with field:
   ```
   clearFault: true (boolean)
   ```
3. Wait up to 30 seconds
4. Check device state

**Expected Results:**
```
✓ Remote command: Clear Fault
[FAULT] Clearing fault state
State: ONLINE
```
- Fault cleared within 30s
- Command document deleted from Firestore
- Device returns to ONLINE
- LED pattern changes to heartbeat

**Pass Criteria:**
- [ ] Command processed within 30s
- [ ] Fault clears successfully
- [ ] Command doc auto-deleted
- [ ] State = ONLINE

---

## ✅ TEST SUITE 7: PERSISTENT STORAGE

### Test 7.1: Config Persistence Across Reboot
**Prerequisites:** Device configured with WiFi

**Steps:**
1. Note current config values from serial
2. Reset ESP8266 (power cycle or reset button)
3. Check if config reloaded

**Expected Results:**
```
✓ Configuration loaded
  SSID: YourNetwork
  Firebase Project: bloom-watch-d6878
  dryThreshold: 520
```
- WiFi credentials restored
- Firebase settings restored
- Thresholds restored
- Reconnects automatically

**Pass Criteria:**
- [ ] /config.json loads successfully
- [ ] WiFi reconnects without portal
- [ ] All settings match pre-reboot

---

### Test 7.2: Pump State Persistence
**Prerequisites:** Pump run at least once

**Steps:**
1. Trigger pump (manual or auto)
2. Note lastPumpEndEpoch, noEffectCounter, lockedFault
3. Reset ESP8266
4. Check serial output on boot

**Expected Results:**
```
✓ Pump state loaded
  Last Pump: XXX sec ago, Fault: NO, No-Effect Count: 0
```
- Last pump time persists
- Fault state persists
- No-effect counter persists
- Used for minInterval calculation

**Pass Criteria:**
- [ ] /pump_state.json loads
- [ ] Last pump time correct
- [ ] Fault state maintained
- [ ] Counter value correct

---

### Test 7.3: Fault State Survives Reboot
**Prerequisites:** Device in LOCKED_FAULT

**Steps:**
1. Trigger fault lock (2x no-effect)
2. Verify LED shows error pattern
3. Reset ESP8266
4. Check state after boot

**Expected Results:**
```
✓ Pump state loaded
  Last Pump: XXX sec ago, Fault: YES, No-Effect Count: 2
State: LOCKED_FAULT
```
- Device boots into LOCKED_FAULT
- LED shows error pattern immediately
- Pump remains disabled
- Must manually clear fault

**Pass Criteria:**
- [ ] Boots with fault active
- [ ] LED error pattern on boot
- [ ] Pump disabled
- [ ] Requires manual intervention

---

## ✅ TEST SUITE 8: WEB INTERFACE

### Test 8.1: Dashboard Access
**Prerequisites:** Device ONLINE, IP address known

**Steps:**
1. Open browser
2. Navigate to http://{device_ip}/
3. Observe dashboard

**Expected Results:**
- HTML dashboard loads
- Shows current status:
  - Device ID
  - State (ONLINE/OFFLINE/FAULT)
  - WiFi status
  - Current moisture reading
  - Pump status
  - Fault status
  - Last pump time

**Pass Criteria:**
- [ ] Dashboard loads < 2 seconds
- [ ] All status fields accurate
- [ ] Auto-refreshes (or manual refresh works)

---

### Test 8.2: Status JSON API
**Prerequisites:** Device ONLINE

**Steps:**
1. GET http://{device_ip}/status
2. Check response format

**Expected Results:**
```json
{
  "deviceId": "ESP8266_C82B9622AF07",
  "state": "ONLINE",
  "moisture": 350,
  "pumpState": "MONITORING",
  "lockedFault": false,
  "wifiConnected": true,
  "lastPumpEpoch": 1234567890,
  "noEffectCounter": 0
}
```

**Pass Criteria:**
- [ ] Returns valid JSON
- [ ] All fields present
- [ ] Values match device state
- [ ] Content-Type: application/json

---

### Test 8.3: Manual Water Endpoint
**Prerequisites:** Device ONLINE, >60s since last pump

**Steps:**
1. POST http://{device_ip}/water
2. Observe pump activation

**Expected Results:**
```
HTTP 200 OK
"Watering started"
```
- Pump activates immediately
- LED shows pumping pattern
- Same safety rules apply
- Logged to Firestore

**Pass Criteria:**
- [ ] Returns 200 status
- [ ] Pump runs for 2 seconds
- [ ] Respects minInterval
- [ ] Blocked if in fault

---

### Test 8.4: Clear Fault Endpoint
**Prerequisites:** Device in LOCKED_FAULT

**Steps:**
1. POST http://{device_ip}/clearFault
2. Check state change

**Expected Results:**
```
HTTP 200 OK
"Fault cleared"
```
- Fault clears immediately
- State changes to ONLINE
- LED pattern updates
- pump_state.json updated

**Pass Criteria:**
- [ ] Returns 200
- [ ] Fault clears
- [ ] Same as long-press button

---

### Test 8.5: Reset WiFi Endpoint
**Prerequisites:** Device ONLINE

**Steps:**
1. POST http://{device_ip}/resetWiFi
2. Observe portal start

**Expected Results:**
```
HTTP 200 OK
"Restarting to configuration portal"
```
- Device enters portal mode
- "Irrigation-Setup" AP appears
- Can reconfigure WiFi
- Same as triple-press button

**Pass Criteria:**
- [ ] Returns 200
- [ ] Portal starts immediately
- [ ] Can reconfigure

---

## 📊 TEST RESULTS SUMMARY SHEET

| Test Suite | Total Tests | Passed | Failed | Notes |
|---|---|---|---|---|
| 1. Initialization | 2 | | | |
| 2. Button Controls | 3 | | | |
| 3. LED Patterns | 8 | | | |
| 4. Pump Safety | 5 | | | |
| 5. WiFi Connectivity | 4 | | | |
| 6. Firestore Integration | 4 | | | |
| 7. Persistent Storage | 3 | | | |
| 8. Web Interface | 5 | | | |
| **TOTAL** | **34** | | | |

---

## 🐛 Issue Tracking Template

### Issue Report Format:
```
Test ID: [e.g., 6.1]
Test Name: [e.g., Log Entry Creation]
Status: FAILED
Date: [YYYY-MM-DD]

Expected Behavior:
[What should happen]

Actual Behavior:
[What actually happened]

Serial Output:
```
[Paste relevant serial output]
```

Steps to Reproduce:
1. [Step 1]
2. [Step 2]
3. [Step 3]

Additional Notes:
[Any other observations]
```

---

## ✅ CRITICAL PATH TESTS (Must Pass)

Before considering Phase 1 complete, these tests MUST pass:

1. **Test 2.1** - Manual water button works
2. **Test 4.1** - minInterval enforcement (safety!)
3. **Test 4.4** - Fault locking works (safety!)
4. **Test 5.1** - WiFi portal configuration
5. **Test 6.1** - Firestore logging works
6. **Test 7.2** - Pump state persists

---

## 📝 Testing Notes

- All tests designed for minimal hardware (can test without water)
- Use serial monitor for detailed diagnostics
- Firebase console for cloud verification
- Timing critical - use stopwatch for LED patterns
- Document all failures with serial output
- Test in order - some tests depend on previous state

**Good luck with testing! 🌱**

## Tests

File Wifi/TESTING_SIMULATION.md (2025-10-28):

# 🎮 Wokwi Simulation Testing Guide

## 📋 Overview
This guide explains how to test the Smart Irrigation System using **Wokwi Simulator** - a virtual hardware environment that runs your ESP8266 code without physical hardware.

---

## 🚀 Quick Start

### Option 1: VS Code with Wokwi Extension (Recommended)

1. **Install Wokwi Extension:**
   ```
   - Open VS Code Extensions (Ctrl+Shift+X)
   - Search for "Wokwi Simulator"
   - Install the extension
   ```

2. **Build Firmware:**
   ```bash
   pio run
   ```

3. **Start Simulation:**
   ```
   - Press F1
   - Type "Wokwi: Start Simulator"
   - Select diagram.json
   ```

4. **Interact with Virtual Hardware:**
   - Click button to test short/long/triple press
   - Adjust potentiometer to simulate moisture changes
   - Watch LED blink patterns
   - See relay activate for pump
   - Monitor serial output

---

### Option 2: Wokwi.com Online Simulator

1. **Upload Project:**
   - Go to https://wokwi.com/
   - Create new project (ESP8266)
   - Upload your diagram.json
   - Upload compiled firmware.bin

2. **Run Simulation:**
   - Click green "Start Simulation" button
   - Interact with components

---

## 🔧 Virtual Hardware Components

### Components in Simulation:

| Component | Pin | Purpose | Interaction |
|---|-----|---|---|
| **ESP8266 DevKit** | - | Main controller | Auto-runs code |
| **Push Button** | D2 (GPIO4) | Control button | Click to press |
| **Blue LED** | D3 (GPIO0) | Status indicator | Observe patterns |
| **Relay Module** | D1 (GPIO5) | Pump control | Watch activation |
| **Potentiometer** | A0 | Moisture sensor | Slide to change value |
| **Resistor 330Ω** | - | LED current limit | - |
| **Resistor 10kΩ** | - | Button pull-up | - |

---

## 🧪 Simulation Test Scenarios

### Test 1: Button Pattern Detection

**Short Press:**
1. Click button quickly (< 1 second hold)
2. Watch serial: `[BUTTON] Short press detected`
3. LED should flash 3 times
4. Relay should activate for 2 seconds

**Long Press:**
1. Click and hold button for 5+ seconds
2. Watch serial: `[BUTTON] Long press detected`
3. Should clear fault if present

**Triple Press:**
1. Click button 3 times rapidly (within 2 seconds)
2. Watch serial: `[BUTTON] Triple press detected`
3. Should start WiFi portal

---

### Test 2: Moisture Threshold Testing

**Dry Soil (Auto Water Trigger):**
1. Slide potentiometer to left (low value < 520)
2. Wait for moisture reading cycle
3. Watch for auto pump activation
4. Serial: `[PUMP] Auto activation requested`

**Wet Soil (No Action):**
1. Slide potentiometer to right (high value > 750)
2. Pump should NOT activate
3. Serial: `[STATUS] Moisture: XXX | Pump: MONITORING`

**Mid-Range (Hysteresis Zone):**
1. Set potentiometer between 520-750
2. Test behavior based on previous state
3. Verify hysteresis logic

---

### Test 3: LED Pattern Observation

**All Patterns Visible:**
- Portal mode → Fast double-blink
- Connecting → Fast blink
- Online → Slow heartbeat
- Pumping → Solid on
- Fault → Slow error blink

**Simulation Advantage:**
- Can slow down time to see exact timing
- Pause to measure intervals
- No physical LED burnout risk

---

### Test 4: Pump Safety (No-Effect Detection)

**Simulate Ineffective Pump:**
1. Set potentiometer to dry (< 520)
2. Click button for manual water
3. **DO NOT move potentiometer** (simulate no water added)
4. Wait 12 seconds (pump run + settle time)
5. Serial should show: `⚠ Pump ineffective! No significant moisture change`

**Trigger Fault Lock:**
1. Repeat above test immediately (after 60s minInterval)
2. Second no-effect should trigger fault
3. Serial: `🚨 FAULT LOCKED`
4. LED pattern changes to error blink

**Verify Fault Persistence:**
1. Click button → pump should NOT activate
2. Serial: `[ERROR] Device in fault state`

---

### Test 5: WiFi Simulation (Limited)

**Note:** Wokwi has **limited WiFi simulation**. WiFi Manager portal won't work fully.

**What Works:**
- Code compiles and runs
- Serial output shows WiFi attempts
- State machine transitions
- Timeout handling

**What Doesn't Work:**
- Actual WiFi connection
- Firebase HTTP requests
- Web server access
- Portal configuration

**Workaround:**
- Test WiFi logic with serial monitoring
- Use offline mode testing
- Verify state transitions
- Check retry intervals in logs

---

## 🎯 Simulation Testing Checklist

### ✅ Tests That Work Great in Simulation:

- [x] **Button debouncing** - Click patterns work perfectly
- [x] **LED patterns** - All visible and measurable
- [x] **Moisture readings** - Potentiometer simulates sensor
- [x] **Pump activation** - Relay visible on/off
- [x] **Timing logic** - minInterval enforcement
- [x] **No-effect detection** - Can manually control moisture
- [x] **Fault locking** - State machine visible
- [x] **Persistent storage** - LittleFS works in simulation
- [x] **State machine** - All transitions testable
- [x] **Serial debugging** - Full console output

### ⚠️ Tests That Are Limited:

- [ ] **WiFi connection** - Can't connect to real network
- [ ] **Firebase API** - HTTP requests won't reach cloud
- [ ] **Web interface** - Can't access in browser
- [ ] **OTA updates** - Not supported
- [ ] **Real-time performance** - Simulation is slower

### ❌ Tests That Need Real Hardware:

- [ ] **Actual water pumping** - Physical relay only clicks
- [ ] **Real moisture sensor** - Needs soil/water
- [ ] **Power consumption** - Not measured
- [ ] **WiFi signal strength** - Virtual only
- [ ] **Long-term stability** - Simulation may crash

---

## 📊 Simulation Workflow Recommendation

### Phase 1: Simulation Testing (80% Coverage)
1. Test all button patterns ✅
2. Verify LED patterns ✅
3. Test pump safety logic ✅
4. Validate state machine ✅
5. Check persistence ✅
6. Debug serial output ✅

### Phase 2: Real Hardware Testing (100% Coverage)
1. Upload to physical ESP8266
2. Test WiFi portal configuration
3. Verify Firebase integration
4. Test with actual moisture sensor
5. Run pump with real water
6. Long-term stability test

---

## 🐛 Common Simulation Issues

### Issue 1: Simulation Won't Start
**Symptoms:** Error loading firmware
**Solution:**
```bash
# Rebuild firmware
pio run

# Check file exists
ls .pio/build/nodemcuv2/firmware.elf
```

### Issue 2: WiFi Features Don't Work
**Expected Behavior:** This is normal in simulation
**Workaround:** Focus on testing offline features

### Issue 3: Serial Monitor Shows Gibberish
**Symptoms:** Random characters
**Solution:** Set baud rate to 115200 in simulator settings

### Issue 4: LittleFS Not Persistent
**Symptoms:** Config lost on restart
**Note:** Some simulators don't persist flash between runs
**Workaround:** Test persistence on real hardware

---

## 📝 Automated Simulation Test Script

Create `test/test_simulation.cpp` for automated checks:

```cpp
#include <unity.h>

// Simulation-friendly unit tests
void test_button_debounce() {
    // Test button state tracking
    TEST_ASSERT_EQUAL(NONE, currentButtonAction);
}

void test_moisture_thresholds() {
    // Test threshold logic
    TEST_ASSERT_TRUE(520 < DRY_THRESHOLD);
    TEST_ASSERT_TRUE(750 > WET_THRESHOLD);
}

void test_pump_timing() {
    // Test timing constants
    TEST_ASSERT_EQUAL(2000, PUMP_RUN_TIME);
    TEST_ASSERT_EQUAL(60, MIN_INTERVAL_SEC);
}

void setup() {
    UNITY_BEGIN();
    RUN_TEST(test_button_debounce);
    RUN_TEST(test_moisture_thresholds);
    RUN_TEST(test_pump_timing);
    UNITY_END();
}

void loop() {}
```

Run with:
```bash
pio test -e nodemcuv2
```

---

## 🎮 Interactive Simulation Controls

### Keyboard Shortcuts (If Supported):
- `B` - Simulate button press
- `M` - Toggle moisture (dry/wet)
- `R` - Reset device
- `P` - Pause simulation
- `S` - Step through code

### Mouse Controls:
- Click button component
- Drag potentiometer slider
- Right-click for component properties

---

## 📈 Simulation Testing Benefits

### Advantages:
✅ **Fast iteration** - No upload delays
✅ **No hardware damage** - Can't burn components
✅ **Repeatable tests** - Exact same conditions
✅ **Debug-friendly** - Pause and inspect
✅ **Free** - No hardware purchase needed
✅ **Shareable** - Share diagram.json with team

### Limitations:
❌ **Not 100% accurate** - Timing may differ
❌ **WiFi limited** - Can't test cloud features
❌ **Performance** - Slower than real hardware
❌ **Environmental factors** - No temperature, humidity, etc.

---

## 🚀 Next Steps After Simulation

1. **Simulation Testing** (You are here)
   - Verify core logic
   - Test button patterns
   - Debug LED patterns
   - Validate pump safety

2. **Upload to Hardware**
   - `pio run --target upload`
   - Test WiFi portal
   - Verify Firebase sync

3. **Field Testing**
   - Real soil/water
   - Long-term monitoring
   - Performance optimization

---

## 📚 Resources

- **Wokwi Docs:** https://docs.wokwi.com/
- **ESP8266 in Wokwi:** https://docs.wokwi.com/parts/wokwi-esp8266-devkit
- **PlatformIO + Wokwi:** https://docs.wokwi.com/vscode/project-config
- **Example Projects:** https://wokwi.com/projects

---

## ✅ Simulation Test Results Template

| Test | Status | Notes |
|---|---|---|
| Button Short Press | ⬜ | |
| Button Long Press | ⬜ | |
| Button Triple Press | ⬜ | |
| LED Portal Pattern | ⬜ | |
| LED Online Pattern | ⬜ | |
| LED Pumping Pattern | ⬜ | |
| LED Fault Pattern | ⬜ | |
| Moisture Reading | ⬜ | |
| Auto Water Trigger | ⬜ | |
| Manual Water | ⬜ | |
| minInterval Enforcement | ⬜ | |
| No-Effect Detection | ⬜ | |
| Fault Locking | ⬜ | |
| Fault Clear | ⬜ | |
| State Persistence | ⬜ | |

**Happy Simulating! 🎮🌱**

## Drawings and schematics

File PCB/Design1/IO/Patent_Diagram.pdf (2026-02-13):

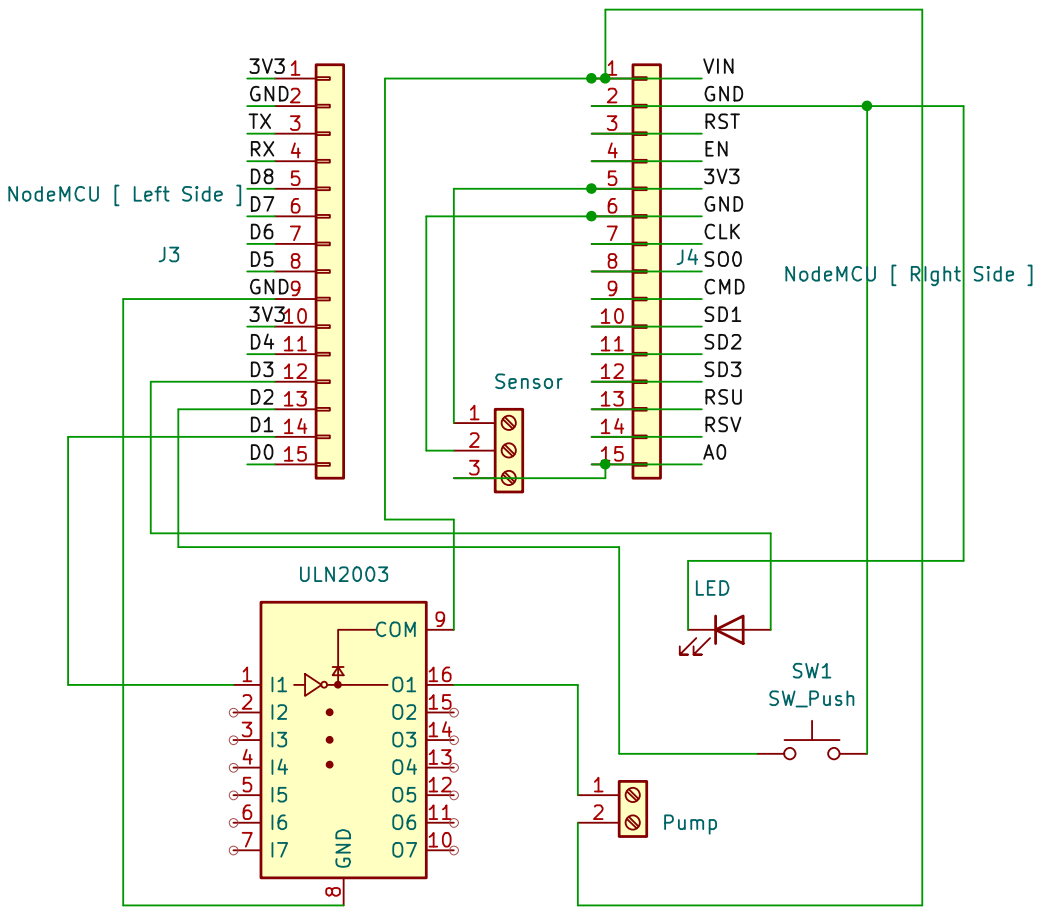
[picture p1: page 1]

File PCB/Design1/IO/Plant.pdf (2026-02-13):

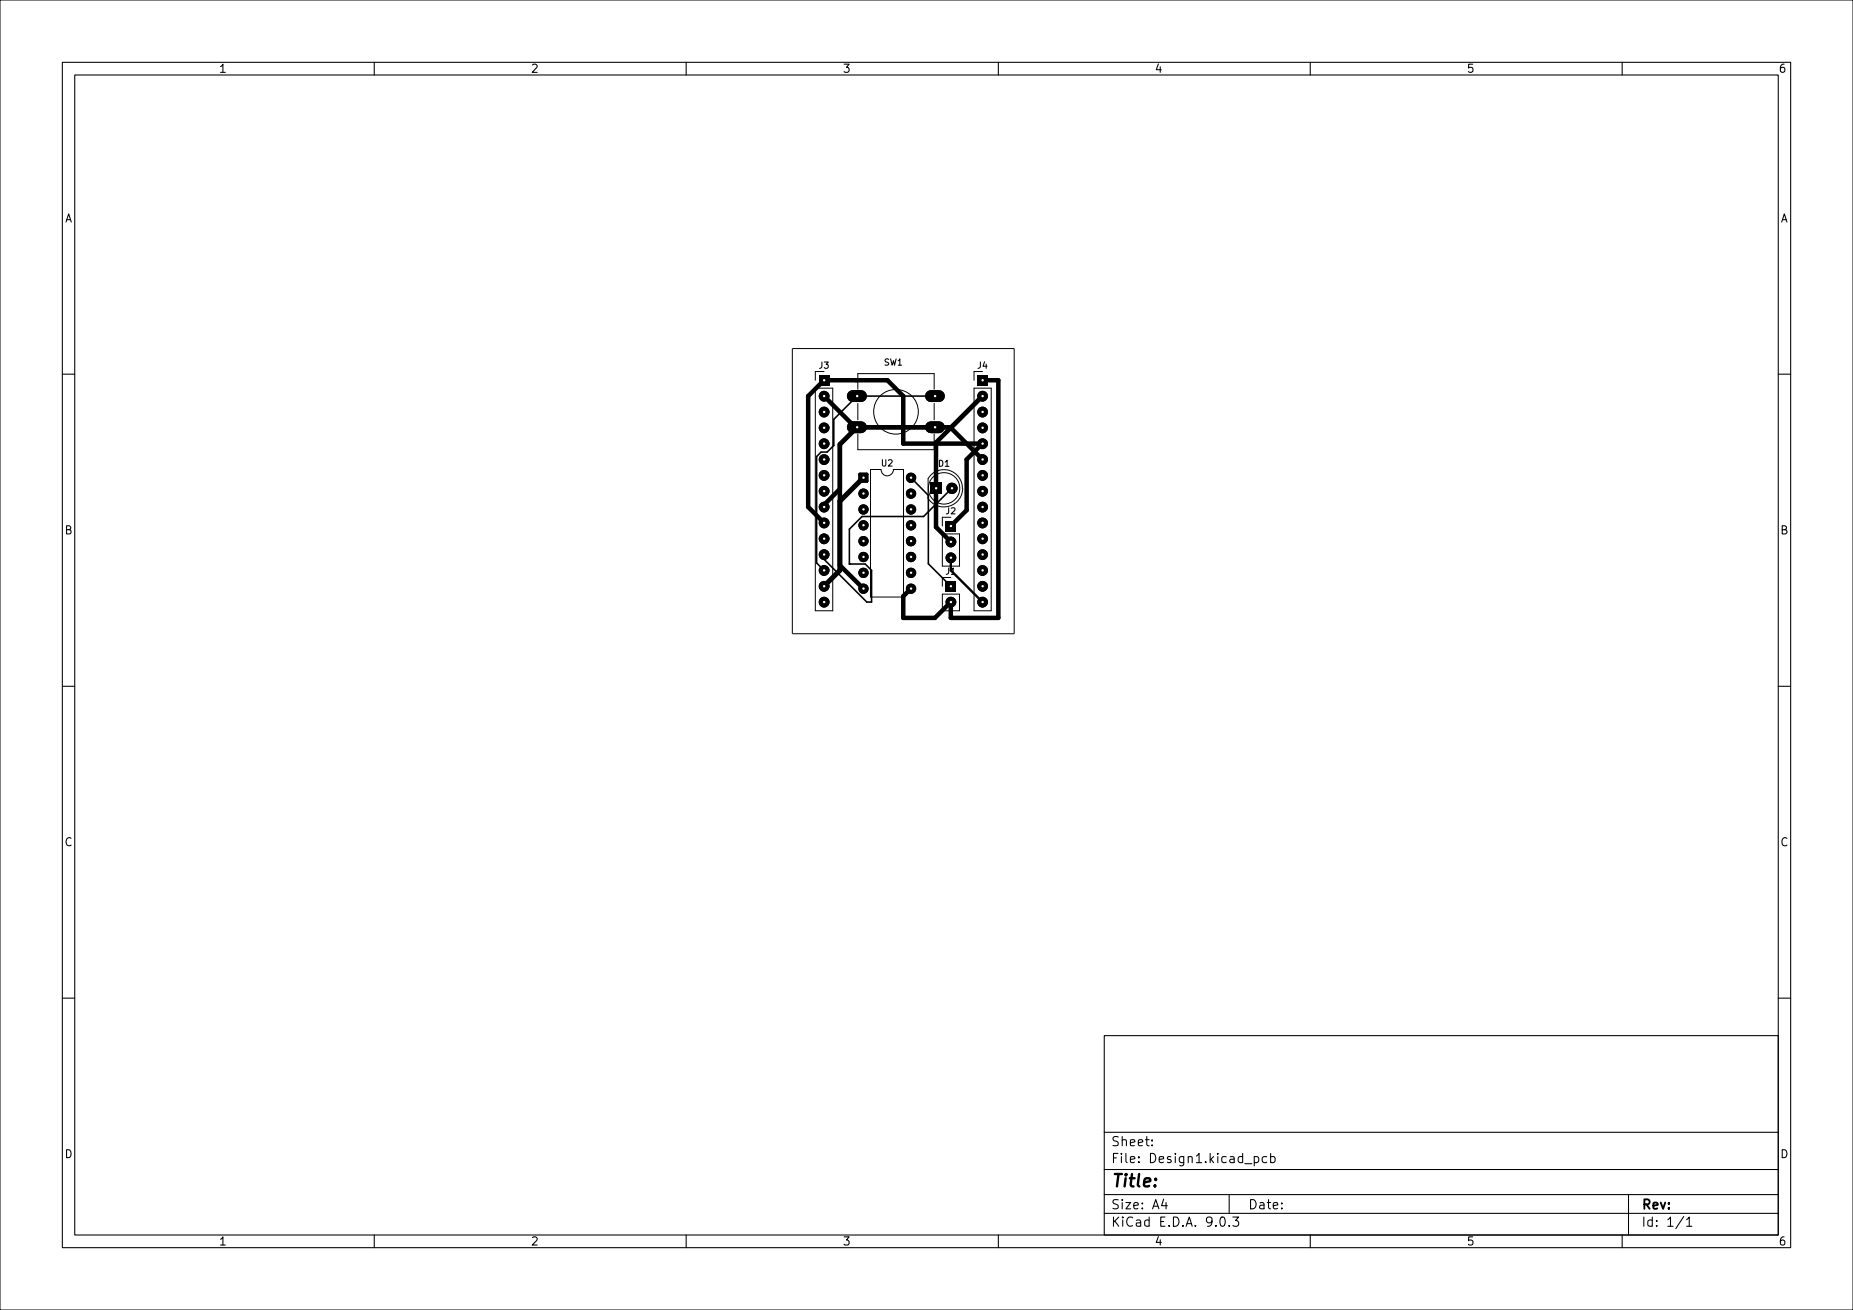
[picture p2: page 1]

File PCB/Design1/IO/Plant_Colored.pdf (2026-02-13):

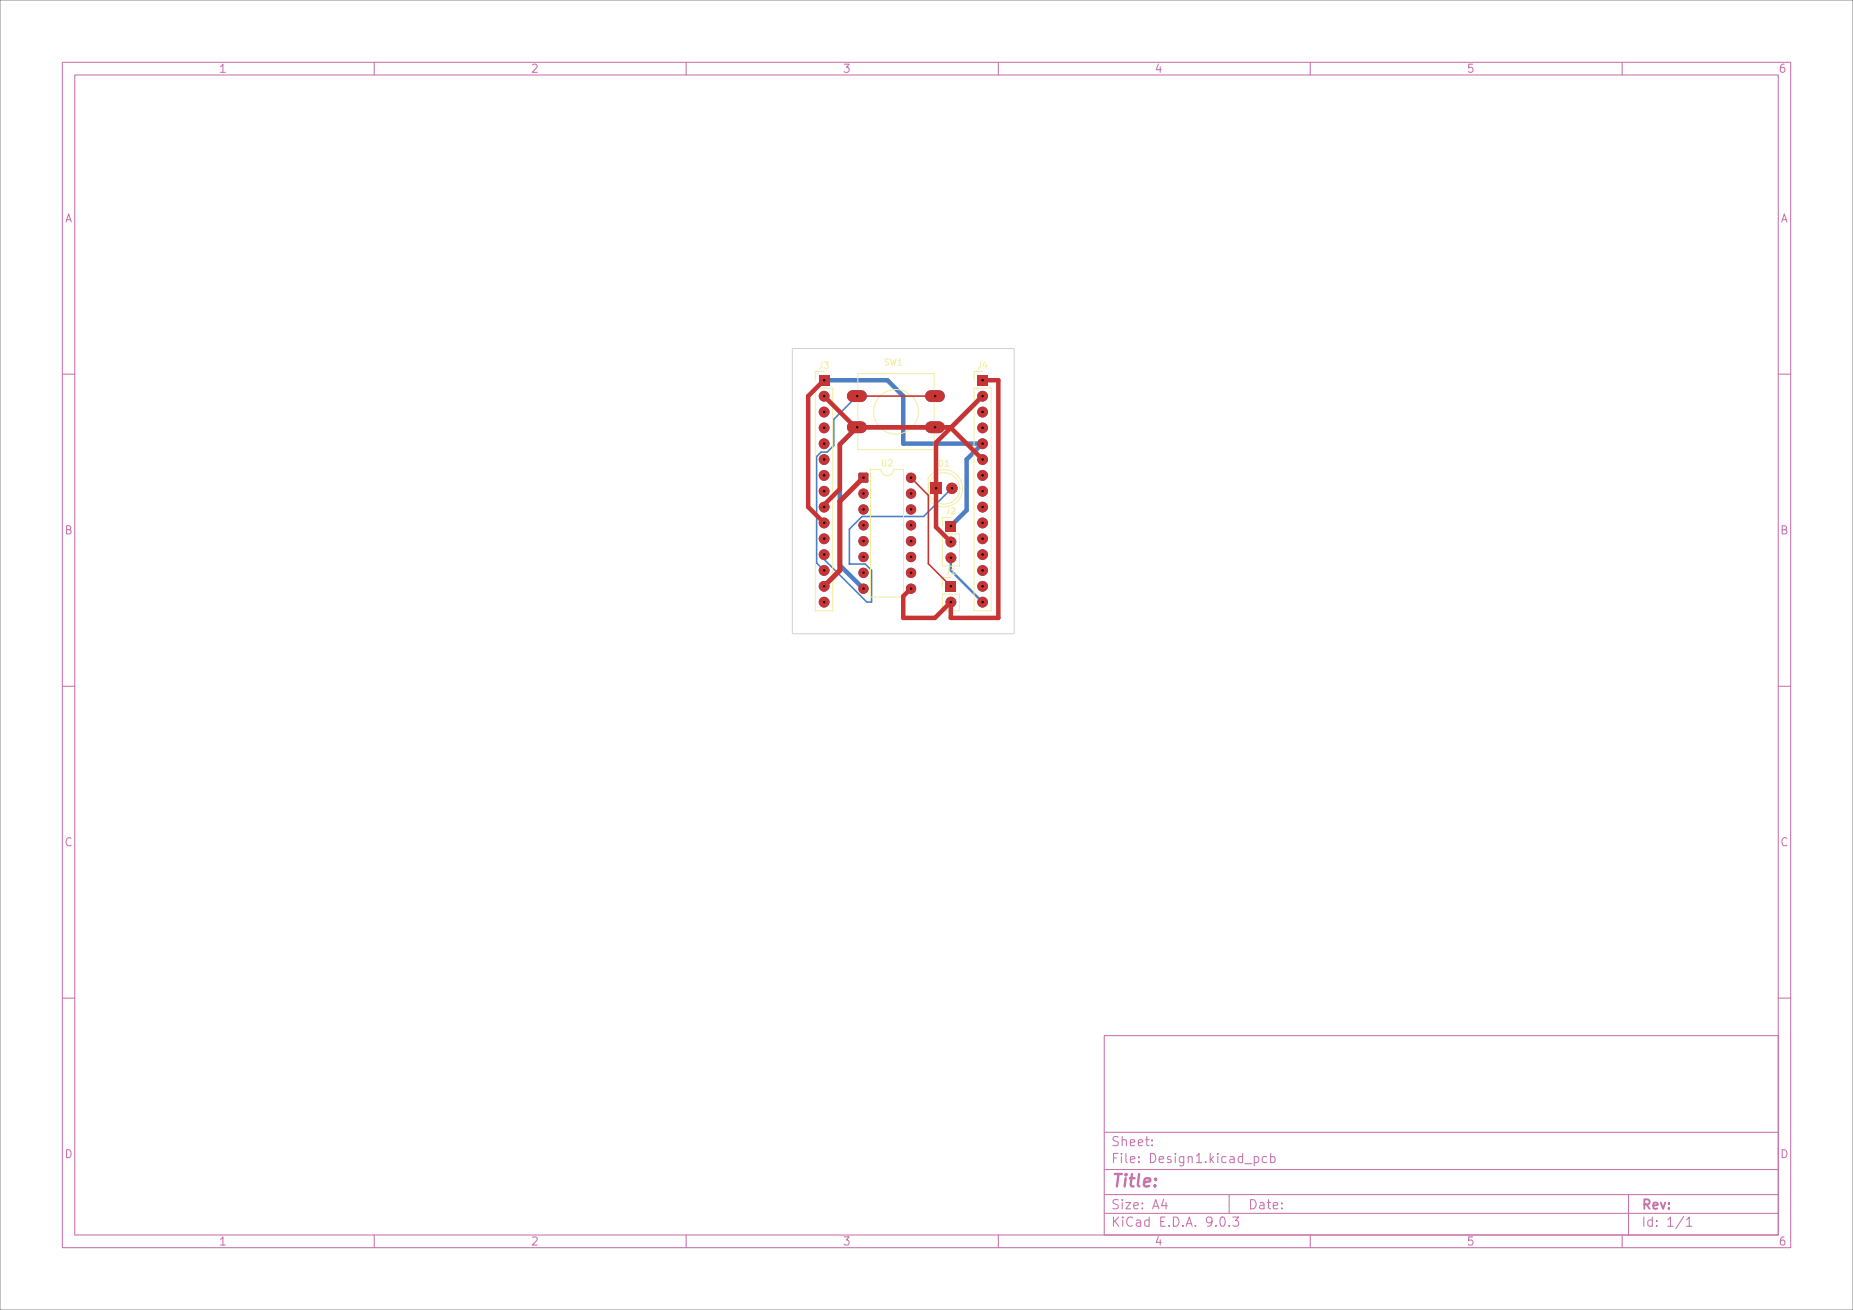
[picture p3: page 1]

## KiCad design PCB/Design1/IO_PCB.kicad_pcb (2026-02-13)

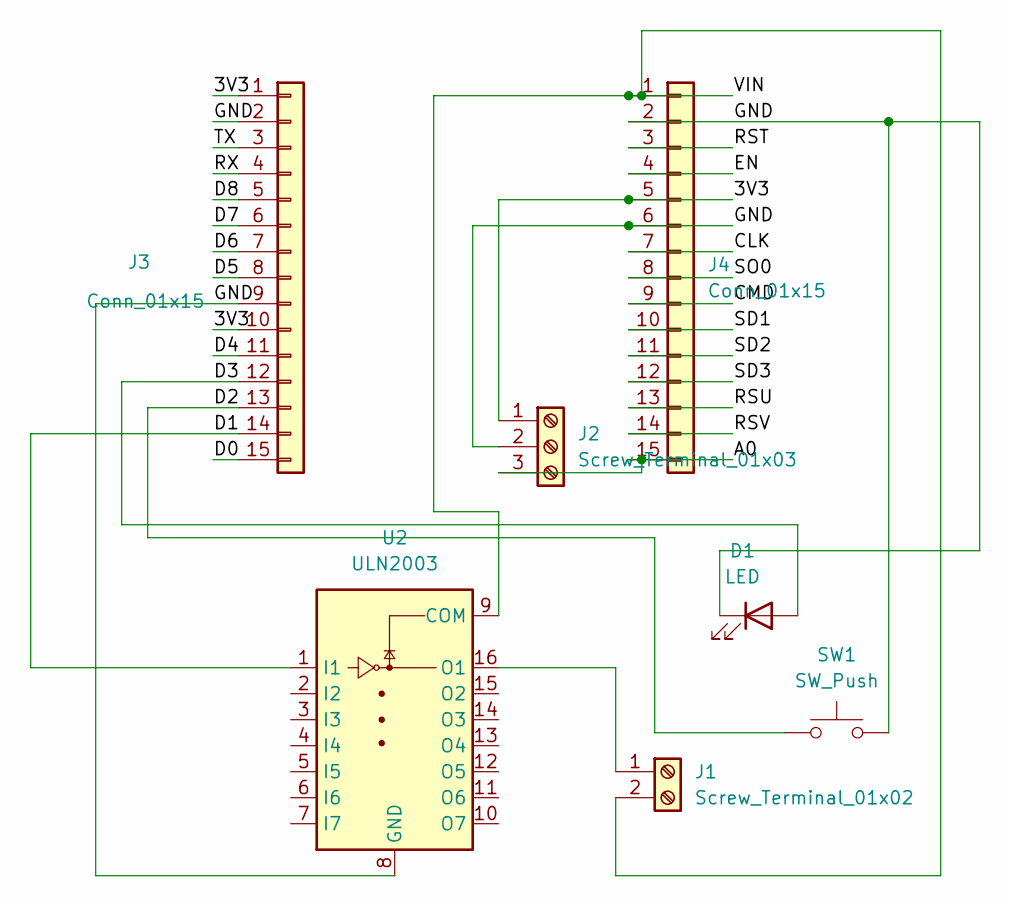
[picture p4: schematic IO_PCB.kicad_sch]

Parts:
D1: LED; LED_D5.0mm
J1: Screw_Terminal_01x02; PinHeader_1x02_P2.54mm_Vertical
J2: Screw_Terminal_01x03; PinHeader_1x03_P2.54mm_Vertical
J3, J4: Conn_01x15; PinHeader_1x15_P2.54mm_Vertical
SW1: SW_Push; SW_PUSH-12mm
U2: ULN2003; DIP-16_W7.62mm

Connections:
/3V3: J2.1, J3.1, J3.10, J4.5
/A0: J2.3, J4.15
/CLK: J4.7
/CMD: J4.9
/D0: J3.15
/D1: J3.14, U2.1 (I1)
/D2: J3.13, SW1.1
/D3: D1.2 (A), J3.12
/D4: J3.11
/D5: J3.8
/D6: J3.7
/D7: J3.6
/D8: J3.5
/EN: J4.4
/GND: D1.1 (K), J2.2, J3.2, J3.9, J4.2, J4.6, SW1.2, U2.8 (GND)
/RST: J4.3
/RSU: J4.13
/RSV: J4.14
/RX: J3.4
/SD1: J4.10
/SD2: J4.11
/SD3: J4.12
/SO0: J4.8
/TX: J3.3
/VIN: J1.2, J4.1, U2.9 (COM)
unnamed: J1.1, U2.16 (O1)

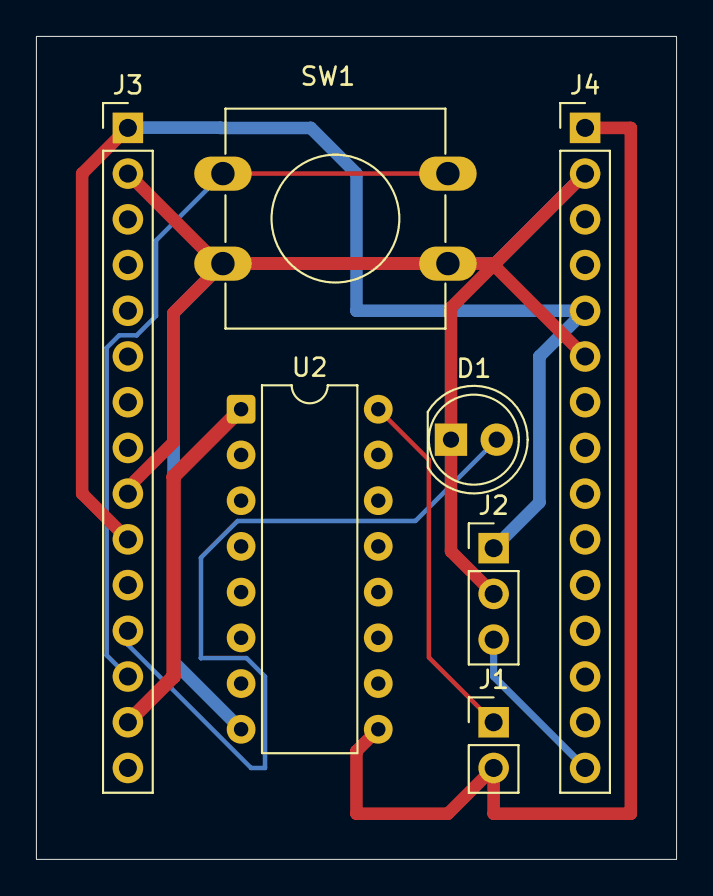
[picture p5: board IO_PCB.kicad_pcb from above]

Board: 2 copper layers, 35.6 x 45.7 mm, 7 parts (0 on the bottom side), 8 nets.

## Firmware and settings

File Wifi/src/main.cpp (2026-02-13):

/*
 * Smart Irrigation System with WiFi and Firebase
 * ESP8266-based automated plant watering with remote monitoring
 */

#include <Arduino.h>
#include <WiFiManager.h>
#include <ESP8266WiFi.h>
#include <LittleFS.h>
#include <ArduinoJson.h>
#include <ESP8266WebServer.h>
#include <ESP8266HTTPClient.h>
#include <WiFiClientSecure.h>
#include <time.h>  // For NTP time sync

// Hardware pin configuration
constexpr uint8_t PUMP_CTRL_PIN = D1;      // ULN2003 IN1
constexpr uint8_t SENSOR_PIN = A0;          // Moisture sensor analog out
constexpr uint8_t BUTTON_PIN = D2;          // Manual control button
constexpr uint8_t LED_PIN = D3;             // Status LED

// Firebase configuration
String firebaseProjectId = "bloom-watch-d6878";
String firebaseApiKey = "YOURAPIKEY";
String firebaseDatabaseURL = "YOURDBURL"; //The old ones have been revoked
String deviceId = "";           // Generated from MAC address

// File system paths
const char* CONFIG_FILE = "/config.json";
const char* PUMP_STATE_FILE = "/pump_state.json";

// Device state machine
enum DeviceState {
    AWAITING_CONFIG,    // No WiFi config, portal active
    ONLINE,             // Connected to WiFi and Firebase
    OFFLINE,            // WiFi not available, operating locally
    LOCKED_FAULT        // Critical fault detected, auto watering disabled
};
DeviceState deviceState = AWAITING_CONFIG;

// Pump state machine
enum PumpState {
    MONITORING,         // Watching sensor, ready to water
    PUMP_RUNNING,       // Actively pumping water
    PUMP_WAITING        // Cooldown period after watering
};
PumpState pumpState = MONITORING;

// Button state tracking
enum ButtonAction {
    NONE,
    SHORT_PRESS,        // Manual watering
    LONG_PRESS,         // Clear fault
    TRIPLE_PRESS        // Force WiFi reset
};

// LED blink patterns
enum LedPattern {
    LED_OFF,                    // Device off or sleeping
    LED_PORTAL_ACTIVE,          // Fast double-blink (portal mode)
    LED_CONNECTING,             // Fast single blink (connecting to WiFi)
    LED_ONLINE,                 // Slow heartbeat (connected and online)
    LED_OFFLINE,                // Single blink every 3 seconds (offline mode)
    LED_PUMPING,                // Solid on (pump running)
    LED_FAULT,                  // Slow error blink (locked fault)
    LED_BUTTON_FEEDBACK         // Quick flash (button acknowledged)
};
LedPattern currentLedPattern = LED_OFF;

// Configuration parameters (can be updated via Firestore)
uint16_t DRY_THRESHOLD = 520;           // Moisture level to trigger watering
uint16_t WET_THRESHOLD = 420;           // Moisture level when soil is wet
unsigned long PUMP_RUN_TIME = 2000;     // 2 seconds pump runtime
unsigned long MIN_INTERVAL_SEC = 30;    // 60 seconds minimum between pump activations (production default)
uint8_t MAX_NO_EFFECT_REPEATS = 10;     // 10 consecutive failures triggers fault (increased for stability)
unsigned long PUMP_SETTLE_MS = 20000;   // 20 seconds wait after pump to re-read sensor

// Timing constants
const unsigned long PORTAL_TIMEOUT = 300000;        // 5 minutes
const unsigned long DATA_SEND_INTERVAL = 30000;     // 30 seconds (data logging interval)
const unsigned long CONFIG_CHECK_INTERVAL = 5000;  // 5 seconds (check for Firestore config updates)
const unsigned long DISPLAY_INTERVAL = 5000;        // 5 seconds (status display interval)
const unsigned long WIFI_CHECK_INTERVAL = 5000;     // 5 seconds
const unsigned long BUTTON_DEBOUNCE_MS = 50;        // 50ms debounce
const unsigned long LONG_PRESS_MS = 5000;           // 5 second long press
const unsigned long TRIPLE_PRESS_WINDOW = 800;      // 0.8 second window for triple press (more responsive)

// Smart Retry Intervals (exponential backoff)
const unsigned long RETRY_INTERVAL_1 = 3600000;     // 1 hour
const unsigned long RETRY_INTERVAL_2 = 21600000;    // 6 hours
const unsigned long RETRY_INTERVAL_3 = 86400000;    // 24 hours// Global state variables
// WiFi & Connectivity
WiFiManager wm;
ESP8266WebServer server(80);
bool wifiConnected = false;
unsigned long lastReconnectAttempt = 0;
unsigned long nextRetryInterval = RETRY_INTERVAL_1;
uint8_t retryCount = 0;

// Timing trackers
unsigned long lastDataSend = 0;
unsigned long lastConfigCheck = 0;
unsigned long lastDisplayTime = 0;
unsigned long lastWiFiCheck = 0;
unsigned long lastLedUpdate = 0;

// Pump state tracking
unsigned long pumpStartTime = 0;
unsigned long lastPumpEndEpoch = 0;     // Epoch seconds of last pump stop
unsigned long lastPumpActionTime = 0;
uint16_t moistureBeforePump = 0;
uint8_t noEffectCounter = 0;
bool lockedFault = false;
String lastActivationMethod = "NONE";

// Button tracking
bool buttonPressed = false;
unsigned long buttonPressStart = 0;
unsigned long lastButtonPress = 0;
uint8_t pressCount = 0;
bool longPressHandled = false;

// LED tracking
bool ledState = false;
unsigned long ledBlinkStart = 0;

// Function declarations
// Device initialization
void initializeFileSystem();
void generateDeviceId();
void loadOrCreateConfig();
void loadPumpState();
void savePumpState();

// WiFi management
void setupWiFi();
void startConfigurationPortal();
void attemptWiFiConnection();
void checkWiFi();
void handleSmartRetry();

// Hardware I/O
ButtonAction readButton();
void updateLED();
void setLedPattern(LedPattern pattern);

// Pump control
void handlePumpStateMachine();
bool checkPumpSafety();
void activatePump(const String& method);
void checkPumpEffectiveness();

// Firestore integration
void syncWithFirestore();
void sendDataToFirestore(uint16_t moisture, const String& pumpStatus, const String& activationMethod);
void updateMainDeviceStatus(uint16_t moisture, const String& pumpStatus);
void checkForConfigUpdates();
void checkForRemoteCommands();
void logEventToFirestore(const String& eventType, const String& details);

// Web server
void setupWebServer();
void handleRoot();
void handleGetStatus();
void handleManualWater();
void handleClearFault();
void handleResetWiFi();

// Utility
String getDeviceStateString();
String getPumpStateString();
unsigned long getCurrentEpoch();

// Setup
void setup() {
    Serial.begin(115200);
    delay(2000);
    Serial.println("\n\n====================================");
    Serial.println("SMART IRRIGATION SYSTEM v3.0");
    Serial.println("Phase 1: Full Design Implementation");
    Serial.println("====================================\n");
    
    // Initialize hardware pins
    pinMode(PUMP_CTRL_PIN, OUTPUT);
    pinMode(BUTTON_PIN, INPUT_PULLUP);
    pinMode(LED_PIN, OUTPUT);
    digitalWrite(PUMP_CTRL_PIN, LOW);
    digitalWrite(LED_PIN, LOW);
    
    // Initialize file system
    initializeFileSystem();
    
    // Generate unique device ID from MAC
    generateDeviceId();
    
    Serial.println("Device ID: " + deviceId);
    Serial.println("Firestore Path: plantData/" + deviceId);
    
    // Load configuration from LittleFS
    loadOrCreateConfig();
    
    // Load pump state (maintains history across reboots)
    loadPumpState();
    
    // Setup WiFi
    setupWiFi();
    attemptWiFiConnection();
    
    // Setup web server
    setupWebServer();
    
    Serial.println("\n====================================");
    Serial.println("INITIALIZATION COMPLETE");
    Serial.println("State: " + getDeviceStateString());
    Serial.printf("Safety Interval: %lu seconds\n", MIN_INTERVAL_SEC);
    Serial.println("====================================");
    Serial.println("ℹ Adjust MIN_INTERVAL_SEC via:");
    Serial.println("  • Web App Dashboard");
    Serial.println("  • Firestore: plantData/" + deviceId + "/config/settings");
    Serial.println("  • Set minIntervalSec to 0-3600 seconds");
    Serial.println("====================================\n");
}

// Main loop
void loop() {
    unsigned long currentTime = millis();
    
    // Handle web server
    server.handleClient();
    
    // Read and handle button actions
    ButtonAction action = readButton();
    switch (action) {
        case TRIPLE_PRESS:
            Serial.println("\n[BUTTON] Triple press detected - Force WiFi reset");
            setLedPattern(LED_BUTTON_FEEDBACK);
            startConfigurationPortal();
            break;
            
        case LONG_PRESS:
            Serial.println("\n[BUTTON] Long press detected - Clear fault");
            setLedPattern(LED_BUTTON_FEEDBACK);
            if (lockedFault) {
                lockedFault = false;
                noEffectCounter = 0;
                savePumpState();
                deviceState = wifiConnected ? ONLINE : OFFLINE;
                logEventToFirestore("fault_cleared", "User cleared fault via button");
                Serial.println("✓ Fault cleared successfully");
            } else {
                Serial.println("ℹ No fault to clear");
            }
            break;
            
        case SHORT_PRESS:
            Serial.println("\n╔═════════════════════════════════════╗");
            Serial.println("║ 🔘 BUTTON: Manual Water Request    ║");
            Serial.println("╚═════════════════════════════════════╝");
            setLedPattern(LED_BUTTON_FEEDBACK);
            if (deviceState != LOCKED_FAULT) {
                if (checkPumpSafety()) {
                    activatePump("MANUAL");
                } else {
                    Serial.println("❌ DENIED: Safety interval not met\n");
                }
            } else {
                Serial.println("❌ DENIED: Device in FAULT state\n");
            }
            break;
            
        case NONE:
            // No button action
            break;
    }
    
    // Update LED status
    updateLED();
    
    // WiFi management
    if (deviceState != AWAITING_CONFIG) {
        checkWiFi();
        if (!wifiConnected && deviceState != LOCKED_FAULT) {
            handleSmartRetry();
        }
    }
    
    // Firestore sync (only when online)
    // Allow sync even in LOCKED_FAULT state so we can receive clear commands
    if (wifiConnected && (deviceState == ONLINE || deviceState == LOCKED_FAULT)) {
        // Send data periodically
        if (currentTime - lastDataSend >= DATA_SEND_INTERVAL) {
            syncWithFirestore();
            lastDataSend = currentTime;
        }
        
        // Check for config updates
        if (currentTime - lastConfigCheck >= CONFIG_CHECK_INTERVAL) {
            checkForConfigUpdates();
            checkForRemoteCommands();
            lastConfigCheck = currentTime;
        }
    }
    
    // Display status on serial
    if (currentTime - lastDisplayTime >= DISPLAY_INTERVAL) {
        uint16_t moisture = analogRead(SENSOR_PIN);
        
        // Compact status line
        Serial.printf("[STATUS] M:%d | P:%s | D:%s | W:%s",
            moisture,
            getPumpStateString().c_str(),
            getDeviceStateString().c_str(),
            wifiConnected ? "ON" : "OFF"
        );
        
        // Add extra info if relevant
        if (lockedFault) Serial.print(" | ⚠️ FAULT");
        if (wifiConnected) Serial.printf(" | RSSI:%ddBm", WiFi.RSSI());
        if (pumpState == PUMP_WAITING) {
            unsigned long currentEpoch = getCurrentEpoch();
            if (currentEpoch > 0 && lastPumpEndEpoch > 0 && currentEpoch >= lastPumpEndEpoch) {
                unsigned long timeSincePump = currentEpoch - lastPumpEndEpoch;
                if (timeSincePump < MIN_INTERVAL_SEC) {
                    unsigned long remaining = MIN_INTERVAL_SEC - timeSincePump;
                    Serial.printf(" | Next:%lus", remaining);
                }
            }
        }
        Serial.println();
        
        lastDisplayTime = currentTime;
    }
    
    // Pump state machine (core irrigation logic)
    handlePumpStateMachine();
    
    delay(10);  // Small delay for stability
}

// File system functions
void initializeFileSystem() {
    if (!LittleFS.begin()) {
        Serial.println("✗ Failed to mount LittleFS");
        Serial.println("⚠ Running without persistent storage");
    } else {
        Serial.println("✓ LittleFS mounted successfully");
    }
}

void generateDeviceId() {
    uint8_t mac[6];
    WiFi.macAddress(mac);
    
    // Format: ESP8266_AABBCCDDEEFF
    char macStr[18];
    sprintf(macStr, "%02X%02X%02X%02X%02X%02X", 
            mac[0], mac[1], mac[2], mac[3], mac[4], mac[5]);
    
    deviceId = "ESP8266_" + String(macStr);
}

void loadOrCreateConfig() {
    if (!LittleFS.exists(CONFIG_FILE)) {
        Serial.println("ℹ No config file found - will create on first WiFi connection");
        return;
    }
    
    File configFile = LittleFS.open(CONFIG_FILE, "r");
    if (!configFile) {
        Serial.println("✗ Failed to open config file");
        return;
    }
    
    JsonDocument doc;
    DeserializationError error = deserializeJson(doc, configFile);
    configFile.close();
    
    if (error) {
        Serial.println("✗ Config JSON parse error: " + String(error.c_str()));
        return;
    }
    
    // Load Firebase credentials if present
    if (doc.containsKey("firebaseProjectId")) {
        firebaseProjectId = doc["firebaseProjectId"].as<String>();
    }
    if (doc.containsKey("firebaseApiKey")) {
        firebaseApiKey = doc["firebaseApiKey"].as<String>();
    }
    
    // Load watering parameters
    DRY_THRESHOLD = doc["dryThreshold"] | DRY_THRESHOLD;
    WET_THRESHOLD = doc["wetThreshold"] | WET_THRESHOLD;
    PUMP_RUN_TIME = doc["pumpRunTime"] | PUMP_RUN_TIME;
    MIN_INTERVAL_SEC = doc["minIntervalSec"] | MIN_INTERVAL_SEC;
    
    Serial.println("✓ Configuration loaded");
    Serial.printf("  Thresholds: Dry=%d, Wet=%d\n", DRY_THRESHOLD, WET_THRESHOLD);
    Serial.printf("  Pump Time: %lu ms, Min Interval: %lu sec\n", PUMP_RUN_TIME, MIN_INTERVAL_SEC);
}

void loadPumpState() {
    if (!LittleFS.exists(PUMP_STATE_FILE)) {
        Serial.println("ℹ No pump state file - starting fresh");
        savePumpState();  // Create initial state file
        return;
    }
    
    File stateFile = LittleFS.open(PUMP_STATE_FILE, "r");
    if (!stateFile) {
        Serial.println("✗ Failed to open pump state file");
        return;
    }
    
    JsonDocument doc;
    DeserializationError error = deserializeJson(doc, stateFile);
    stateFile.close();
    
    if (error) {
        Serial.println("✗ Pump state JSON parse error: " + String(error.c_str()));
        return;
    }
    
    lastPumpEndEpoch = doc["lastPumpEndEpoch"] | 0;
    lockedFault = doc["lockedFault"] | false;
    noEffectCounter = doc["noEffectCounter"] | 0;
    
    Serial.println("✓ Pump state loaded");
    Serial.printf("  Last Pump: %lu sec ago, Fault: %s, No-Effect Count: %d\n", 
                  getCurrentEpoch() - lastPumpEndEpoch,
                  lockedFault ? "YES" : "NO",
                  noEffectCounter);
    
    if (lockedFault) {
        deviceState = LOCKED_FAULT;
        setLedPattern(LED_FAULT);
    }
}

void savePumpState() {
    JsonDocument doc;
    doc["lastPumpEndEpoch"] = lastPumpEndEpoch;
    doc["lockedFault"] = lockedFault;
    doc["noEffectCounter"] = noEffectCounter;
    doc["deviceId"] = deviceId;
    
    File stateFile = LittleFS.open(PUMP_STATE_FILE, "w");
    if (!stateFile) {
        Serial.println("✗ Failed to save pump state");
        return;
    }
    
    if (serializeJson(doc, stateFile) == 0) {
        Serial.println("✗ Failed to write pump state JSON");
    }
    
    stateFile.close();
}

// WiFi management
void setupWiFi() {
    WiFi.mode(WIFI_STA);
    WiFi.setSleepMode(WIFI_NONE_SLEEP);
    WiFi.setAutoReconnect(true);
    WiFi.persistent(true);
    
    wm.setConnectTimeout(30);
    wm.setConfigPortalTimeout(PORTAL_TIMEOUT / 1000);  // Convert to seconds
}

void startConfigurationPortal() {
    Serial.println("\n[WiFi] Starting configuration portal");
    deviceState = AWAITING_CONFIG;
    setLedPattern(LED_PORTAL_ACTIVE);
    
    WiFi.disconnect(true);
    delay(1000);
    
    if (!wm.startConfigPortal("Irrigation-Setup", "plant123456")) {
        Serial.println("✗ Portal timeout - restarting");
        ESP.restart();
        return;
    }
    
    // Save configuration
    String ssid = WiFi.SSID();
    String pass = WiFi.psk();
    
    JsonDocument doc;
    doc["ssid"] = ssid;
    doc["pass"] = pass;
    doc["firebaseProjectId"] = firebaseProjectId;
    doc["firebaseApiKey"] = firebaseApiKey;
    doc["dryThreshold"] = DRY_THRESHOLD;
    doc["wetThreshold"] = WET_THRESHOLD;
    doc["pumpRunTime"] = PUMP_RUN_TIME;
    doc["minIntervalSec"] = MIN_INTERVAL_SEC;
    
    File configFile = LittleFS.open(CONFIG_FILE, "w");
    if (configFile) {
        serializeJson(doc, configFile);
        configFile.close();
        Serial.println("✓ Configuration saved");
    }
    
    wifiConnected = true;
    deviceState = ONLINE;
    setLedPattern(LED_ONLINE);
    retryCount = 0;
    nextRetryInterval = RETRY_INTERVAL_1;
    
    // Initialize NTP for accurate timestamps (UTC+0)
    configTime(0, 0, "pool.ntp.org", "time.nist.gov");
    Serial.print("⏰ Syncing time with NTP");
    
    // Wait up to 10 seconds for time sync
    int retries = 0;
    while (time(nullptr) < 100000 && retries < 20) {
        delay(500);
        Serial.print(".");
        retries++;
    }
    
    time_t now = time(nullptr);
    if (now >= 100000) {
        Serial.println(" ✓");
        Serial.printf("  Unix timestamp: %lu (GMT)\n", (unsigned long)now);
        struct tm timeinfo;
        gmtime_r(&now, &timeinfo);
        Serial.printf("  Date/Time: %04d-%02d-%02d %02d:%02d:%02d UTC\n",
                     timeinfo.tm_year + 1900, timeinfo.tm_mon + 1, timeinfo.tm_mday,
                     timeinfo.tm_hour, timeinfo.tm_min, timeinfo.tm_sec);
    } else {
        Serial.println(" ✗ FAILED");
        Serial.println("  ⚠️  Timestamps will be 0 until sync succeeds");
    }
}

void attemptWiFiConnection() {
    if (!LittleFS.exists(CONFIG_FILE)) {
        Serial.println("ℹ No WiFi config - starting portal");
        startConfigurationPortal();
        return;
    }
    
    // Load saved credentials
    File configFile = LittleFS.open(CONFIG_FILE, "r");
    if (!configFile) {
        startConfigurationPortal();
        return;
    }
    
    JsonDocument doc;
    DeserializationError error = deserializeJson(doc, configFile);
    configFile.close();
    
    if (error) {
        startConfigurationPortal();
        return;
    }
    
    String ssid = doc["ssid"].as<String>();
    String pass = doc["pass"].as<String>();
    
    if (ssid.length() == 0) {
        startConfigurationPortal();
        return;
    }
    
    Serial.println("\n[WiFi] Attempting connection to: " + ssid);
    setLedPattern(LED_CONNECTING);
    
    WiFi.begin(ssid.c_str(), pass.c_str());
    
    unsigned long startTime = millis();
    while (WiFi.status() != WL_CONNECTED && millis() - startTime < 15000) {
        delay(500);
        Serial.print(".");
    }
    Serial.println();
    
    if (WiFi.status() == WL_CONNECTED) {
        wifiConnected = true;
        deviceState = lockedFault ? LOCKED_FAULT : ONLINE;
        setLedPattern(lockedFault ? LED_FAULT : LED_ONLINE);
        Serial.println("✓ WiFi connected");
        Serial.println("  IP: " + WiFi.localIP().toString());
        
        // Initialize NTP for accurate timestamps (UTC+0)
        configTime(0, 0, "pool.ntp.org", "time.nist.gov");
        Serial.print("⏰ Syncing time with NTP");
        
        // Wait up to 10 seconds for time sync
        int retries = 0;
        while (time(nullptr) < 100000 && retries < 20) {
            delay(500);
            Serial.print(".");
            retries++;
        }
        
        time_t now = time(nullptr);
        if (now >= 100000) {
            Serial.println(" ✓");
            Serial.printf("  Unix timestamp: %lu (GMT)\n", (unsigned long)now);
            struct tm timeinfo;
            gmtime_r(&now, &timeinfo);
            Serial.printf("  Date/Time: %04d-%02d-%02d %02d:%02d:%02d UTC\n",
                         timeinfo.tm_year + 1900, timeinfo.tm_mon + 1, timeinfo.tm_mday,
                         timeinfo.tm_hour, timeinfo.tm_min, timeinfo.tm_sec);
        } else {
            Serial.println(" ✗ FAILED");
            Serial.println("  ⚠️  Timestamps will be 0 until sync succeeds");
        }
        
        retryCount = 0;
        nextRetryInterval = RETRY_INTERVAL_1;
    } else {
        wifiConnected = false;
        deviceState = lockedFault ? LOCKED_FAULT : OFFLINE;
        setLedPattern(lockedFault ? LED_FAULT : LED_OFFLINE);
        Serial.println("✗ WiFi connection failed - entering offline mode");
        Serial.println("  Next retry in: " + String(nextRetryInterval / 60000) + " minutes");
        lastReconnectAttempt = millis();
    }
}

void checkWiFi() {
    unsigned long currentTime = millis();
    if (currentTime - lastWiFiCheck < WIFI_CHECK_INTERVAL) return;
    lastWiFiCheck = currentTime;
    
    if (WiFi.status() != WL_CONNECTED) {
        if (wifiConnected) {
            Serial.println("✗ WiFi connection lost");
            wifiConnected = false;
            deviceState = lockedFault ? LOCKED_FAULT : OFFLINE;
            setLedPattern(lockedFault ? LED_FAULT : LED_OFFLINE);
            lastReconnectAttempt = currentTime;
        }
    } else if (!wifiConnected) {
        Serial.println("✓ WiFi reconnected");
        wifiConnected = true;
        deviceState = lockedFault ? LOCKED_FAULT : ONLINE;
        setLedPattern(lockedFault ? LED_FAULT : LED_ONLINE);
        
        // Re-sync NTP time after reconnection
        configTime(0, 0, "pool.ntp.org", "time.nist.gov");
        Serial.println("⏰ Re-syncing NTP time...");
        retryCount = 0;
        nextRetryInterval = RETRY_INTERVAL_1;
    }
}
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

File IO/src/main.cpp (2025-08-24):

#include <Arduino.h>

constexpr uint8_t PUMP_CTRL_PIN = D1;   // ULN2003 IN1/O1
constexpr uint8_t SENSOR_PIN = A0;      // Moisture sensor output
constexpr uint16_t DRY_THRESHOLD = 480; // Start pumping when moisture reaches 480 (higher = drier)
constexpr uint16_t WET_THRESHOLD = 440; // Stop pumping when moisture reaches 440 or below

// Timing variables
unsigned long lastDisplayTime = 0;           // For 3-second display updates
unsigned long lastPumpActionTime = 0;        // For pump cycle timing
const unsigned long DISPLAY_INTERVAL = 3000; // 3 seconds in milliseconds
const unsigned long PUMP_RUN_TIME = 2000;    // 2 second pump run time
const unsigned long PUMP_WAIT_TIME = 60000; // 1 minutes wait time (60 seconds)

// Pump state variables
enum PumpState
{
  MONITORING,   // Waiting for moisture to reach 480
  PUMP_RUNNING, // Pump is currently running
  PUMP_WAITING  // Waiting 1 minutes before next check
};

PumpState currentState = MONITORING;
unsigned long pumpStartTime = 0;

void setup()
{
  Serial.begin(115200);
  pinMode(PUMP_CTRL_PIN, OUTPUT);
  digitalWrite(PUMP_CTRL_PIN, LOW); // pump OFF

  Serial.println("Smart Irrigation System Started");
  Serial.println("Dry threshold: 520, Wet threshold: 420");
  Serial.println("Display updates every 3 seconds");
}

void loop()
{
  unsigned long currentTime = millis();

  // 1. Display moisture reading every 3 seconds
  if (currentTime - lastDisplayTime >= DISPLAY_INTERVAL)
  {
    uint16_t displayMoisture = analogRead(SENSOR_PIN);
    Serial.print("Moisture Level: ");
    Serial.print(displayMoisture);
    Serial.print(" | State: ");

    switch (currentState)
    {
    case MONITORING:
      Serial.println("MONITORING");
      break;
    case PUMP_RUNNING:
      Serial.println("PUMP_RUNNING");
      break;
    case PUMP_WAITING:
      Serial.println("PUMP_WAITING");
      break;
    }

    lastDisplayTime = currentTime;
  }

  // 2. State machine for pump control
  switch (currentState)
  {
  case MONITORING:
  {
    uint16_t moisture = analogRead(SENSOR_PIN);
    if (moisture >= DRY_THRESHOLD)
    {
      // Soil is dry (520 or higher) → start pumping
      digitalWrite(PUMP_CTRL_PIN, HIGH);
      currentState = PUMP_RUNNING;
      pumpStartTime = currentTime;
      Serial.println("PUMP: ON (moisture >= 520)");
    }
  }
  break;

  case PUMP_RUNNING:
    if (currentTime - pumpStartTime >= PUMP_RUN_TIME)
    {
      // Turn pump OFF after 1 second
      digitalWrite(PUMP_CTRL_PIN, LOW);
      currentState = PUMP_WAITING;
      lastPumpActionTime = currentTime;
      Serial.println("PUMP: OFF (1 second completed, waiting 2 minutes)");
    }
    break;

  case PUMP_WAITING:
    if (currentTime - lastPumpActionTime >= PUMP_WAIT_TIME)
    {
      // 2 minutes have passed, check moisture level
      uint16_t moisture = analogRead(SENSOR_PIN);
      Serial.print("2-minute check - Moisture: ");
      Serial.println(moisture);

      if (moisture <= WET_THRESHOLD)
      {
        // Soil is wet enough (420 or below) → stop pumping cycle
        currentState = MONITORING;
        Serial.println("TARGET REACHED: Moisture <= 420, returning to monitoring");
      }
      else
      {
        // Still too dry → pump again for 1 second
        digitalWrite(PUMP_CTRL_PIN, HIGH);
        currentState = PUMP_RUNNING;
        pumpStartTime = currentTime;
        Serial.println("PUMP: ON again (moisture still > 420)");
      }
    }
    break;
  }
}

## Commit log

2025-08-24 Add offline-first logic and manual pump control
    Refactored main loop to support offline-first operation, enabling core irrigation logic and status display without WiFi. Added manual pump activation via button, LED status indicators for system and 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
2025-10-28 Add Phase 1 docs and update config for ESP8266
    Added comprehensive documentation: HARDWARE_GUIDE.md, PHASE1_IMPLEMENTATION.md, QUICK_REFERENCE.md, and README_DEPLOYMENT.md for the Smart Irrigation System. Updated platformio.ini with correct library versions and ESP8266 dependencies. Overhauled main.cpp to implement full Phase 1 features per specification, including hardware integration, button/LED controls, pump safety, persistent storage, device ID, WiFi management, Firestore integration, and web interface.
    [main.cpp]
2025-10-28 Improve serial output and Firestore logging
    Enhanced serial output formatting for button presses, pump activation, and effectiveness checks to improve readability. Updated Firestore logging to include additional device metrics such as WiFi RSSI, uptime, fault status, and timestamp. Improved status display and error handling for Firestore operations.
    [main.cpp]
2025-10-28 Use Firebase server timestamp for lastSeen field
    Replaces the ESP8266 epoch time with Firebase's server timestamp for the lastSeen field in device status updates. This ensures more accurate and consistent time tracking across devices.
    [main.cpp]
2025-10-29 Improve triple and short press detection logic
    Refactored button press handling to immediately detect triple presses on the third press and delay short press detection until the triple press window expires. This prevents short presses from being incorrectly registered as part of a triple press sequence and ensures more reliable button action recognition.
    [main.cpp]
2025-10-29 Speed up testing and improve NTP sync logging
    Reduced delays and intervals for faster testing, including setting MIN_INTERVAL_SEC to 0 and shortening pump settle time. Enhanced NTP time synchronization feedback with detailed timestamp output and more retries in both configuration portal and WiFi connection routines. Configuration and pump state are now forcibly reset for immediate test cycles.
    [main.cpp]
2025-11-02 Update Firebase credentials in main.cpp
    Replaced the Firebase API key and database URL with placeholders, as the previous credentials have been revoked.
    [main.cpp]
2025-11-06 Update config defaults and remove testing overrides
    Changed configuration parameter defaults to production values and removed code that forcibly set MIN_INTERVAL_SEC to 0 for testing. Updated comments and serial output to clarify configuration via Firestore and web dashboard. Pump state is now loaded instead of reset for testing.
    [main.cpp]
2025-12-19 Adjust pump logic and Firestore sync for stability
    Reduced MIN_INTERVAL_SEC to 30s, increased MAX_NO_EFFECT_REPEATS to 10, and extended PUMP_SETTLE_MS to 20s for improved reliability. Firestore sync and status updates now occur even in LOCKED_FAULT state to allow remote recovery. Refined pump effectiveness logic for capacitive sensors and improved status display timing calculations.
    [main.cpp]
2025-12-19 Add initial Design1 PCB files and backups
    Added KiCad PCB, schematic, project, and related files for Design1, including IO board, Gerber outputs, DRC report, and multiple backup archives. This commit establishes the initial hardware design a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
    [Design1-B_Cu.gbr, Design1-B_Mask.gbr, Design1-Edge_Cuts.gbr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]
